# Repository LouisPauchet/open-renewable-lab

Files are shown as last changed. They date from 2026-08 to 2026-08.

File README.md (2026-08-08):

# Walter Sensor Node — Open Renewable Lab (UNIS)

ESP-IDF firmware for a student-configurable environmental datalogger/gateway
built on the Walter ESP32-S3 module + Walter Feels carrier board: SDI-12 and
I2C sensors (including a built-in PV voltage/current sensing input), SD card
logging, MQTT (WiFi or cellular transport), GNSS position logging (cellular
only), scheduled batch MQTT transmission for power saving, and a
captive-portal web UI for setup - no code changes needed per deployment.

Every device has a stable ID derived from its factory MAC address, shown in
the portal's status panel, written into every CSV file's header line, and
included in every MQTT topic (`<topic_prefix>/<device_id>/<variable name>`)
so multiple nodes can share one broker/topic_prefix.

📖 **Full documentation site:** https://\<OWNER\>.github.io/\<REPO\>/ — start
there for a browsable version of everything below, including a
[step-by-step guide to wiring up a 20 W solar panel and getting data into
ThingsBoard](docs/getting-started.md).

## Get firmware onto a board — no ESP-IDF required

Every [release](https://github.com/<OWNER>/<REPO>/releases) publishes a
ready-to-flash binary. Flash it from your browser (Chrome/Edge, no installs)
or with `esptool` — see **[docs/firmware-downloads.md](docs/firmware-downloads.md)**.
The steps below (`idf.py build`) are only needed if you're modifying the
firmware source.

## Documentation

- **[docs/getting-started.md](docs/getting-started.md)** - wiring up a real
  20 W RS PRO solar panel (voltage + current sensing) and getting its data
  into ThingsBoard over MQTT, start to finish.
- **[docs/USER_MANUAL.md](docs/USER_MANUAL.md)** - deploying and operating a
  device via the web portal. No code or ESP-IDF knowledge needed; start here
  if you're a student setting up a sensor station.
- **[docs/hardware.md](docs/hardware.md)** - photos of the physical
  enclosure, what each external connector is for, and links to the
  KiCad/CAD source.
- **[docs/firmware-downloads.md](docs/firmware-downloads.md)** - getting
  pre-built firmware onto a board without installing ESP-IDF.
- **[docs/DEVELOPER_GUIDE.md](docs/DEVELOPER_GUIDE.md)** - firmware
  architecture, component reference, REST API, concurrency model, and how to
  extend the code (e.g. add a new sensor driver). Start here if you're
  reading or modifying the source.

## Prerequisites

- ESP-IDF **v6.0.2**, target `esp32s3`.
- Network access at build time: `dptechnics/walter-modem` is fetched from the
  ESP Component Registry via `main/idf_component.yml`.
- **Check your ESP-IDF install has the `mqtt` component's source** before
  building: `components/mqtt/esp-mqtt/include` should exist. If it doesn't
  (missing submodule), re-run the ESP-IDF installer / `git submodule update`
  first - this was missing in the environment this firmware was written in,
  so it was never build-tested end-to-end.

## Build

```
idf.py set-target esp32s3
idf.py build
idf.py -p <PORT> flash monitor
```

**No Walter Feels board yet?** You can test the firmware on a plain ESP32
DevKit V1 with I2C sensors (e.g. two ADS1115 ADCs) instead - see
[DEVELOPER_GUIDE.md §19](docs/DEVELOPER_GUIDE.md#19-testing-without-walter-feels-hardware).

## Before first flash: check `board_pins.h`

`components/board_pins/include/board_pins.h` holds every Walter Feels GPIO
assignment. SDI-12, I2C, and SD card pin *numbers* come straight from the
schematic and are confirmed; enable-pin polarities and a few optional pins
(card-detect, status LED, force-AP button) are not - see
[DEVELOPER_GUIDE.md §8](docs/DEVELOPER_GUIDE.md#8-board-pin-mapping-board_pins)
for the full pin table and what's still open. Each subsystem safely no-ops
(logs a warning, falls back to a synthetic stub sensor where relevant) if
its required pins are left unset, so the firmware boots and the portal
works even before any of this is resolved.

For a full list of known low-confidence areas (cellular/GNSS integration,
the SDI-12 physical layer, etc.) that should be reviewed before a real
deployment, see
[DEVELOPER_GUIDE.md §18](docs/DEVELOPER_GUIDE.md#18-known-limitations-and-low-confidence-areas).

## First boot

See [USER_MANUAL.md](docs/USER_MANUAL.md) for the full walkthrough. Short
version: connect to the `WalterSensor-XXXX` WiFi hotspot, browse to
`http://192.168.4.1/` if the login page doesn't pop up automatically, log
in with the default password `walter1234`, and **change it immediately**.

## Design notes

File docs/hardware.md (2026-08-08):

# Hardware

This page documents the physical Open Renewable Lab enclosure — what's
inside it, what each external connector is for, and where to find the
CAD/schematic source if you're building or repairing one.

## The enclosure

<figure markdown>
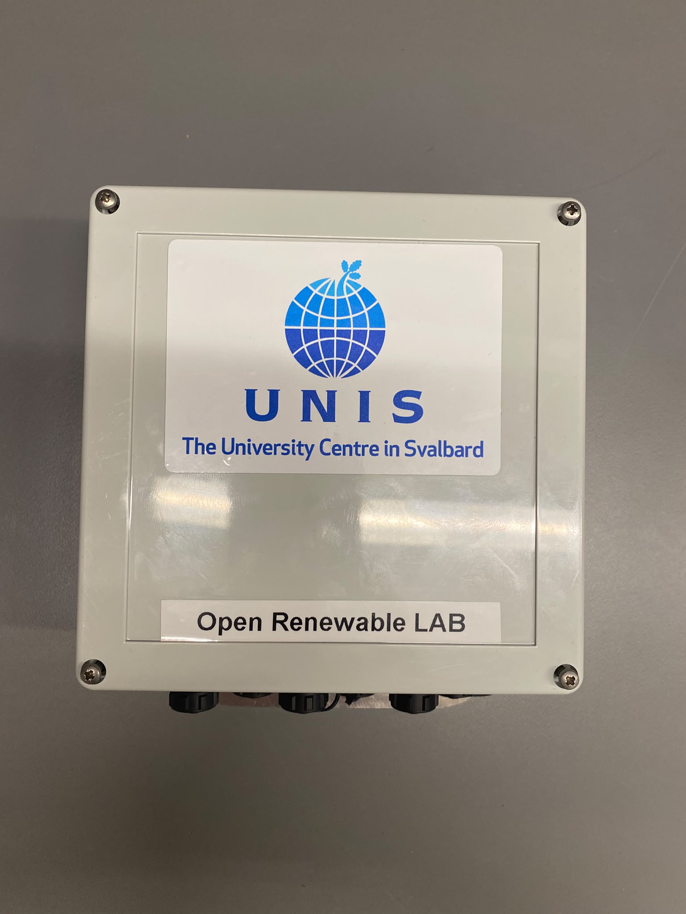
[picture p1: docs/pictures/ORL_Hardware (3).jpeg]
Open Renewable Lab enclosure lid, branded with the UNIS logo

<figcaption>
The enclosure lid: UNIS (The University Centre in Svalbard) branding and
the "Open Renewable LAB" label.
</figcaption>
</figure>

<figure markdown>
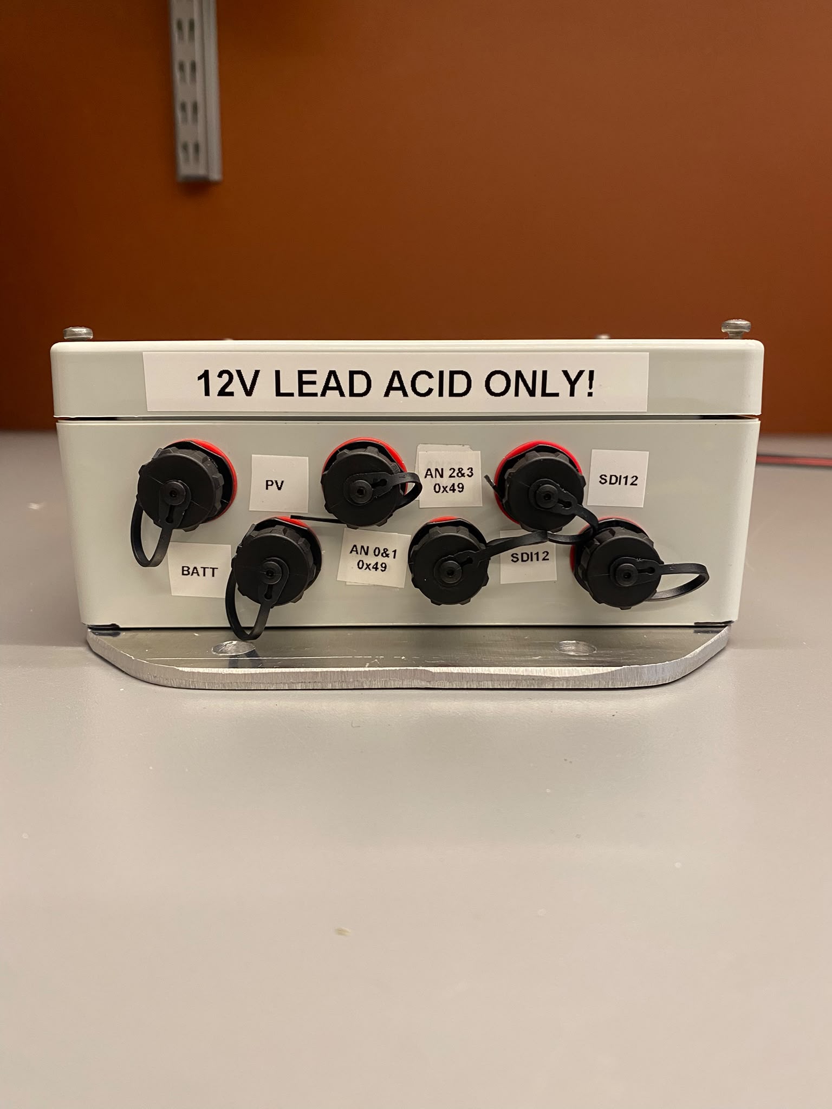
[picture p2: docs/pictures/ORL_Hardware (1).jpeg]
Open Renewable Lab enclosure, external connectors

<figcaption>
The enclosure's external cable glands, each labeled with what it connects
to. "12V LEAD ACID ONLY!" is a hardware constraint on the battery input —
the onboard LTC4015 charger circuit is built for a 12&nbsp;V lead-acid
battery specifically; check with your instructor before connecting a
different battery chemistry.
</figcaption>
</figure>

### Connector reference

| Label | Connects to | Notes |
|---|---|---|
| **PV** | A small auxiliary solar panel, wired straight to the onboard LTC4015 charger | Keeps the logger's *own* operating battery topped up. **Not a measurement input** — this is not where an instrumented/monitored panel goes; see **AN 0&1**/**AN 2&3** below for that. |
| **AN 0&1** (0x49) | A 4-pin instrumented sensor (e.g. the RS PRO panel in [Getting started](getting-started.md)), via the external ADS1115 ADC at I2C address `73` (`0x49`) | Exposes single-ended channels `AIN0`/`AIN1`. For the PV add-on: `AIN0` = voltage (divider output), `AIN1` = current (shunt voltage). |
| **AN 2&3** (0x49) | Same ADS1115, a second 4-pin instrumented sensor input | Exposes single-ended channels `AIN2`/`AIN3` — same wiring pattern as AN 0&1, for a second instrumented sensor (e.g. a second panel, a pyranometer). |
| **BATT** | The 12&nbsp;V lead-acid battery, read by the onboard LTC4015 battery monitor (I2C address `104`/`0x68`) | Set battery chemistry/cell count under the portal's **Battery monitor** settings — see [USER_MANUAL.md §6.5](USER_MANUAL.md#65-onboard-walter-feels-sensors-battery-temperature-humidity-pressure). |
| **SDI12** (×2) | External SDI-12 sensors (soil moisture, weather stations, etc.) | Multiple SDI-12 sensors can share one bus, each with its own address — see [USER_MANUAL.md §6.2](USER_MANUAL.md#62-finding-your-sensors-address). |

`AN 0&1`/`AN 2&3` are generic analog inputs — this enclosure is built on
the same base as the plain [datalogger](build_datalogger.md), with the PV
sensing add-on (ADS1115 + shunt + divider) wired to those two ports rather
than being a fixed, PV-only circuit.

⚠ **AN 0&1, AN 2&3, and BATT (the LTC4015) all need a battery connected
to work at all.** They share one I2C bus, powered from a "Feels 5V" rail
derived from the battery/PV input — USB alone doesn't power it. Bench
testing over USB only, with nothing on BATT, will make that whole bus
look dead/unresponsive; that's expected, not a fault.

## Inside the enclosure

<figure markdown>
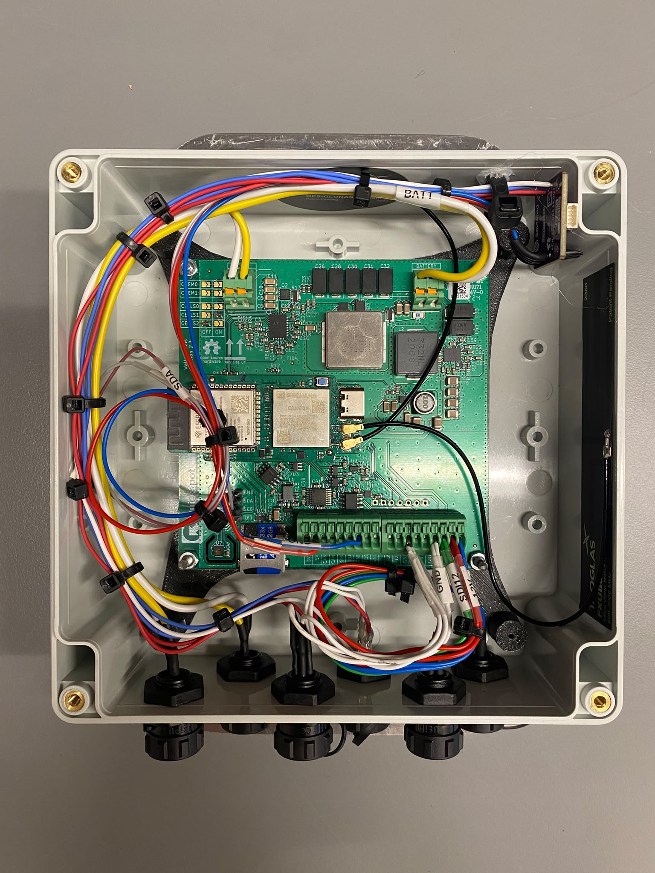
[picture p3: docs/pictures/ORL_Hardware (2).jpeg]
Open enclosure showing the Walter ESP32-S3 board and internal wiring

<figcaption>
The Walter ESP32-S3 module + Walter Feels carrier board, with the GNSS
antenna, battery connector, microSD slot, and the screw-terminal block used
for SDI-12 wiring.
</figcaption>
</figure>

## CAD and schematic source

The full KiCad project (schematic + PCB) for the sensing/interconnect board
lives in the repository under
[`hardware/open_renewable_lab/`](https://github.com/<OWNER>/<REPO>/tree/main/hardware/open_renewable_lab),
open it with [KiCad](https://www.kicad.org/) 8 or newer.

The 3D-printable/CNC enclosure mount is under
[`hardware/drawing/`](https://github.com/<OWNER>/<REPO>/tree/main/hardware/drawing):
`OpenRenewableLabMount.stl` (print-ready), `OpenRenewableLabMount.CATPart`
(CATIA source), and `OpenRenewableLabMount.3mf`.

For the firmware-side GPIO pin mapping that corresponds to this hardware
(SDI-12, I2C, SD card pins), see
[DEVELOPER_GUIDE.md §8](DEVELOPER_GUIDE.md#8-board-pin-mapping-board_pins).

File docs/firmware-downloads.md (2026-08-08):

# Firmware downloads

Every [GitHub Release](https://github.com/<OWNER>/<REPO>/releases) publishes
ready-to-flash firmware binaries automatically — you do **not** need to
install ESP-IDF or build anything to get firmware onto a board. Pick one of
the first two options below; the third is only for people modifying the
firmware source.

## Option 1: Flash from your browser (easiest)

Works in **Chrome or Edge** (desktop) via WebSerial — nothing to install.

1. Plug the board into your computer over USB.
2. Click the button below and follow the prompts (pick the right serial
   port, then "Install").

<script type="module" src="https://unpkg.com/esp-web-tools@10/dist/web/install-button.js"></script>

<esp-web-install-button manifest="../manifest.json">
  <button slot="activate">Connect and flash latest firmware</button>
  <span slot="unsupported">
    Your browser doesn't support WebSerial — use Chrome or Edge, or see
    Option 2 below.
  </span>
  <span slot="not-allowed">
    This page needs to be served over HTTPS to flash (the GitHub Pages
    site already is) — if you're seeing this locally, use Option 2.
  </span>
</esp-web-install-button>

This always flashes the **latest published release**. It erases the whole
flash (including any saved portal configuration) and writes the merged
firmware image in one shot, starting fresh — see
[USER_MANUAL.md](USER_MANUAL.md) afterwards for first-boot setup.

## Option 2: Flash with `esptool` (no ESP-IDF)

1. Install [`esptool`](https://docs.espressif.com/projects/esptool/en/latest/esp32/):
   ```sh
   pip install esptool
   ```
2. Download `walter_sensor_node.merged.bin` from the
   [latest release](https://github.com/<OWNER>/<REPO>/releases/latest).
3. Flash it to offset `0x0` (it already contains the bootloader, partition
   table, and application — no other files or offsets needed):
   ```sh
   esptool.py --chip esp32s3 --port <PORT> write_flash 0x0 walter_sensor_node.merged.bin
   ```
   Replace `<PORT>` with your board's serial port (e.g. `COM5` on Windows,
   `/dev/ttyUSB0` on Linux, `/dev/cu.usbserial-*` on macOS).

Each release also publishes the three components separately
(`bootloader.bin`, `partition-table.bin`, `walter_sensor_node.bin`) and a
`SHA256SUMS` file, in case you need to flash/verify them individually.

## Option 3: Build from source

Only needed if you're modifying the firmware itself. Requires installing
ESP-IDF v6.0.2 — see
[DEVELOPER_GUIDE.md §2](DEVELOPER_GUIDE.md#2-prerequisites-and-build).

## Which release should I use?

Use the [latest release](https://github.com/<OWNER>/<REPO>/releases/latest)
unless your instructor tells you otherwise (e.g. to match a specific lab
session or reproduce a known-good setup).

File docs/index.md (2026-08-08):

# Open Renewable Lab

The **Open Renewable Lab** is UNIS's (The University Centre in Svalbard)
student-configurable environmental datalogger/gateway, built on the Walter
ESP32-S3 module and the Walter Feels carrier board. It reads SDI-12 and I2C
sensors (including a built-in PV voltage/current sensing input), logs to a
microSD card, and publishes to an MQTT broker over WiFi or cellular — all
configured through a web page served by the device itself, with **no code
changes needed per deployment**.

Every device has a stable ID derived from its factory MAC address, shown in
the portal's status panel, written into every CSV file's header line, and
included in every MQTT topic, so multiple nodes can share one broker.

## Where to start

**Building the hardware from parts?** Step-by-step assembly of the
enclosure, wiring, and board — see
[Build a datalogger](build_datalogger.md).

**New to the lab?** Wiring up a real 20 W solar panel and getting live data
into ThingsBoard, start to finish — see
[Getting started](getting-started.md).

**Just need firmware on a board?** Flash a pre-built binary straight from
your browser or with `esptool` — no ESP-IDF install required — see
[Firmware downloads](firmware-downloads.md).

**Operating a device day-to-day?** Sensors, MQTT, SD logging, the web
portal — the full reference for anyone deploying or running a station — see
the [User manual](USER_MANUAL.md).

**Reading or modifying the firmware?** Architecture, component reference,
REST API, and how to extend the code — see the
[Developer guide](DEVELOPER_GUIDE.md).

## What it can do

- Read **SDI-12** sensors (soil moisture, weather stations, water level
  probes) and **I2C** sensors (ADCs, onboard battery/temperature/humidity/
  pressure sensors).
- Log everything to a **microSD card** as CSV files.
- Publish data to an **MQTT broker** over WiFi or cellular (4G/LTE-M/NB-IoT),
  including a ThingsBoard-compatible "flat telemetry" mode — see
  [Getting started](getting-started.md).
- Report **GPS position** over cellular.
- Be fully configured **without writing any code** — every sensor, timing
  setting, and network/MQTT credential is set through the device's own
  captive-portal web page.

## Hardware

The lab's physical build — enclosure, connectors, and PV sensing input — is
documented with photos on the [Hardware](hardware.md) page.

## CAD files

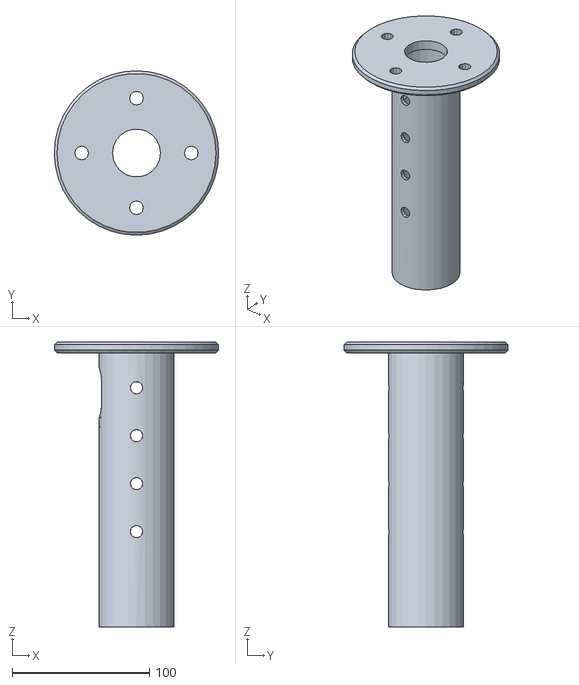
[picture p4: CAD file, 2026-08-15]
hardware/drawing/MountWindTurbine.stl
120.0 x 120.0 x 208.0

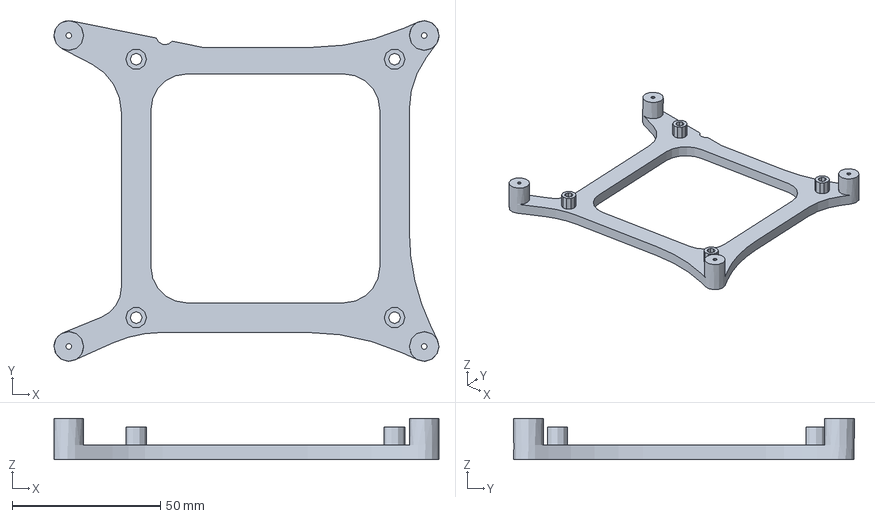
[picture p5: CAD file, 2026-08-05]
hardware/drawing/OpenRenewableLabMount.3mf
130.0 x 115.0 x 14.0 mm

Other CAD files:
hardware/drawing/MountWindTurbine.CATPart
hardware/drawing/OpenRenewableLabMount.CATPart
hardware/drawing/OpenRenewableLabMount.stl

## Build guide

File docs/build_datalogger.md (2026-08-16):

# Let's use this project to build a data logger capable to use any SDI12 sensors.

## What do you need ?

The numbers below match the callouts on the component photo referenced
throughout the steps that follow.

1 - Walter Feels Carrier Board https://www.gotronic.fr/art-module-walter-feels-39900.htm
2 - Walter ESP32 https://www.gotronic.fr/art-carte-walter-esp32-s3-39898.htm
3 - A box RSPRO 672365 https://fr.rs-online.com/web/p/boitiers-pour-usage-general/0672365
4 - A 3D printed support to hold the walter feels in the box
5 - 1 or more SP11 3 Pin connectors (Male and Female) (SDI12 Sensors)
6 - 2x SP11 2 Pin connectors (Male and Female) (Battery and Solar Panel)
7 - Wires
8 - LTE Antenna TAOGLAS FXUB63 https://www.gotronic.fr/art-antenne-flexible-4g-et-5g-fxub63-39916.htm
9 - GNSS Antenna TAOGLAS FXP-611 https://www.gotronic.fr/art-antenne-cloud-gnss-fxp611-39917.htm
10 - A pokawoke to drill in the box (available in AGF dept if you are at UNIS)

<figure markdown>
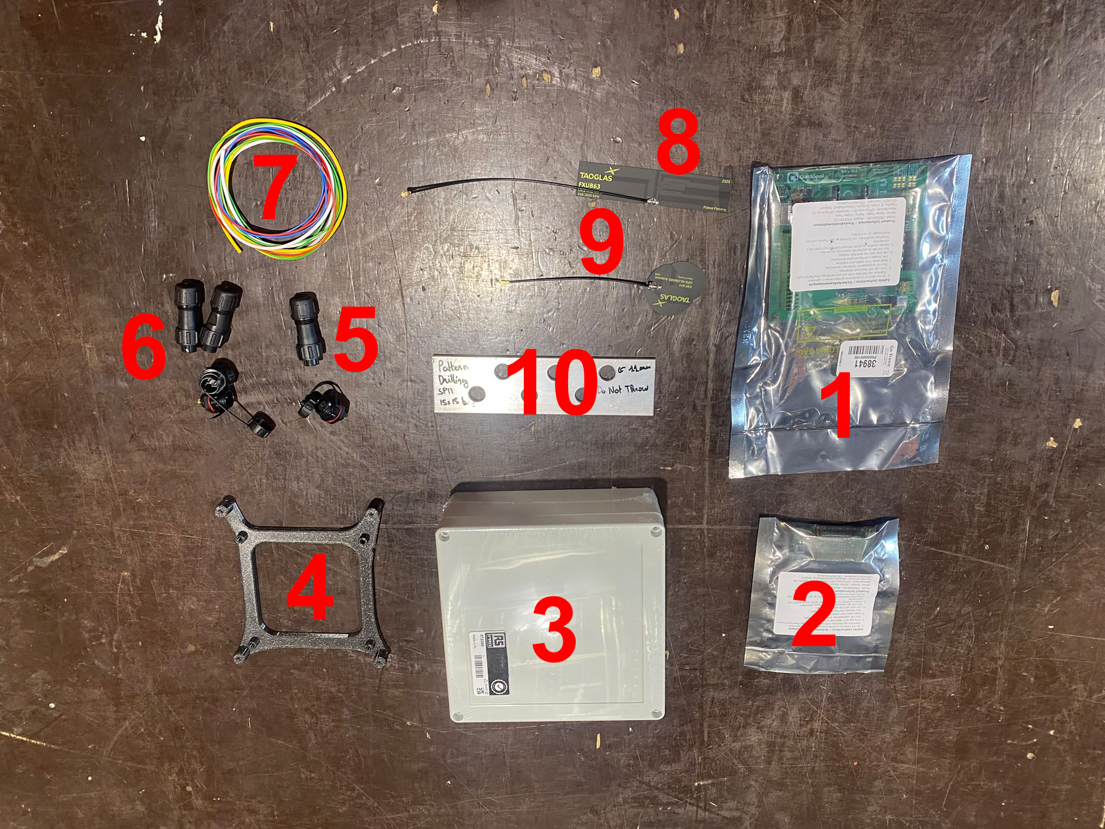
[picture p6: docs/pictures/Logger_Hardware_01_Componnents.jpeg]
Componnent List

<figcaption>
Componnent List
</figcaption>
</figure>

You'll also need a soldering iron, heat shrink tubing (+ a lighter or hot
air gun to shrink it), wire strippers, and a screwdriver.

This page builds the **generic datalogger** - Walter, Walter Feels, box,
antennas, battery/solar charging power, and SDI-12. It does not cover the
ADS1115 analog-input add-on (the two 4-pin "AN1"/"AN2" connectors reading
an instrumented source like a solar panel's or wind turbine's voltage/
current) - if you're building an **Open Renewable Lab** station
specifically, come back to
[Getting started](getting-started.md) and [Hardware](hardware.md) once
this base build is done.

## Building it

### 1. Drill the enclosure

<figure markdown>
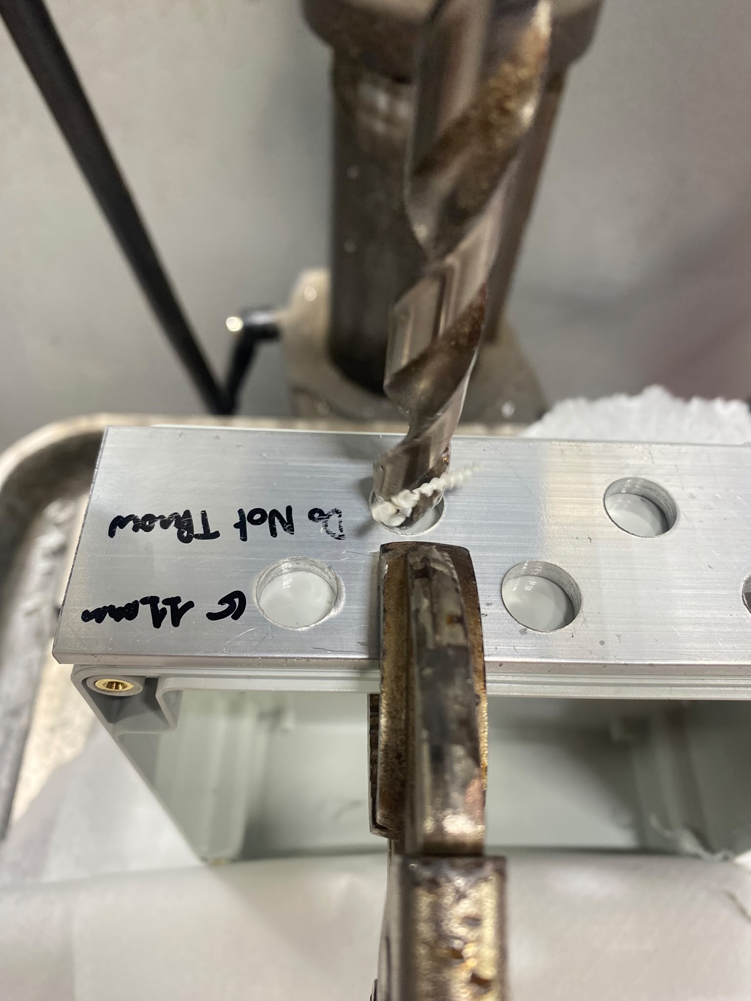
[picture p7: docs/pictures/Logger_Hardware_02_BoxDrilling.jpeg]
Drilling the SP11 connector holes using a jig

<figcaption>
Drilling the box (item 3) for the SP11 connectors, using a reusable
drilling jig/template (labeled "Pattern Drilling SP11 - Do Not Throw") to
keep every hole's position and spacing consistent across builds.
</figcaption>
</figure>

### 2. Solder the power plugs (battery + solar charging)

<figure markdown>
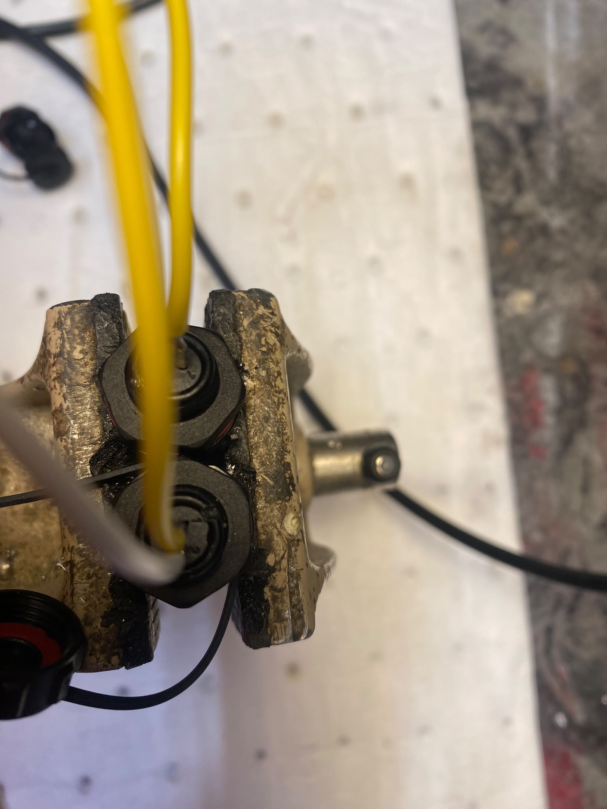
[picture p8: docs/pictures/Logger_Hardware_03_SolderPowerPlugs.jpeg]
Soldering wires onto an SP11 2-pin connector

<figcaption>
Soldering wires onto the two SP11 2-pin connectors (item 6) - one for the
battery, one for the solar panel that charges it. Get the polarity right
and consistent between both connectors before shrinking anything down over
the joints.
</figcaption>
</figure>

<figure markdown>
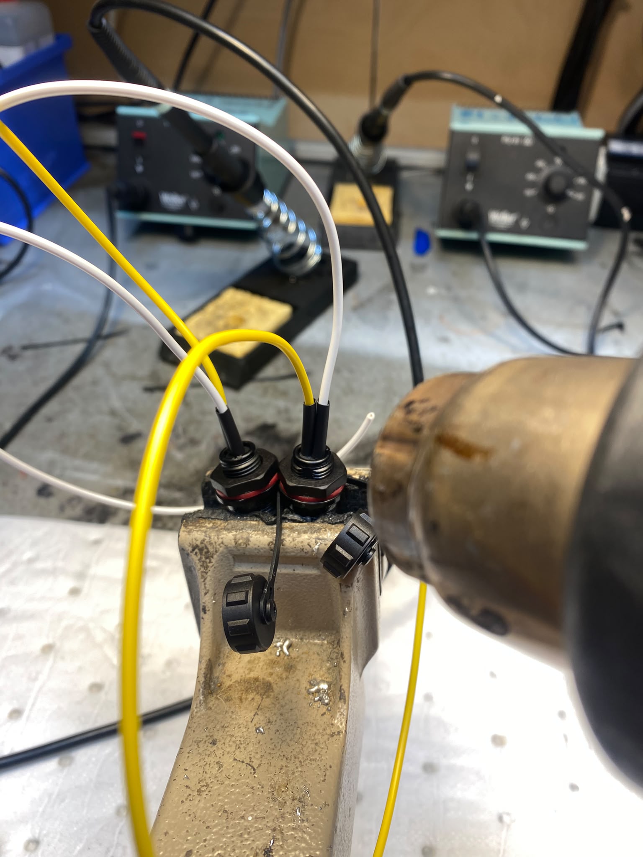
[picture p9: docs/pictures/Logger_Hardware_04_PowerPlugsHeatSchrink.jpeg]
Heat-shrink tubing over the finished power plug solder joints

<figcaption>
Heat-shrink over each solder joint once you're happy with it - both for
strain relief and to keep the two adjacent pins from ever shorting.
</figcaption>
</figure>

### 3. Solder the SDI-12 plug(s)

<figure markdown>
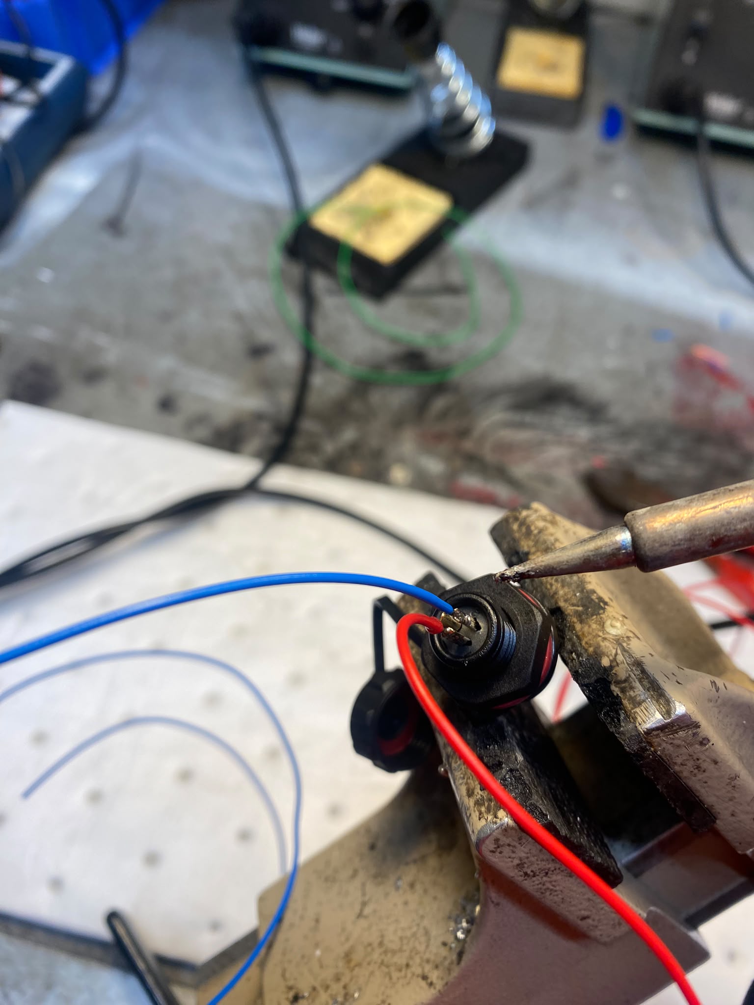
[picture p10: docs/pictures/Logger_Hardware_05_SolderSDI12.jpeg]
Soldering wires onto an SP11 3-pin connector for SDI-12

<figcaption>
Same idea for the SP11 3-pin connector(s) (item 5) - one per SDI-12 port
you want on the box (three wires: signal, power, ground).
</figcaption>
</figure>

<figure markdown>
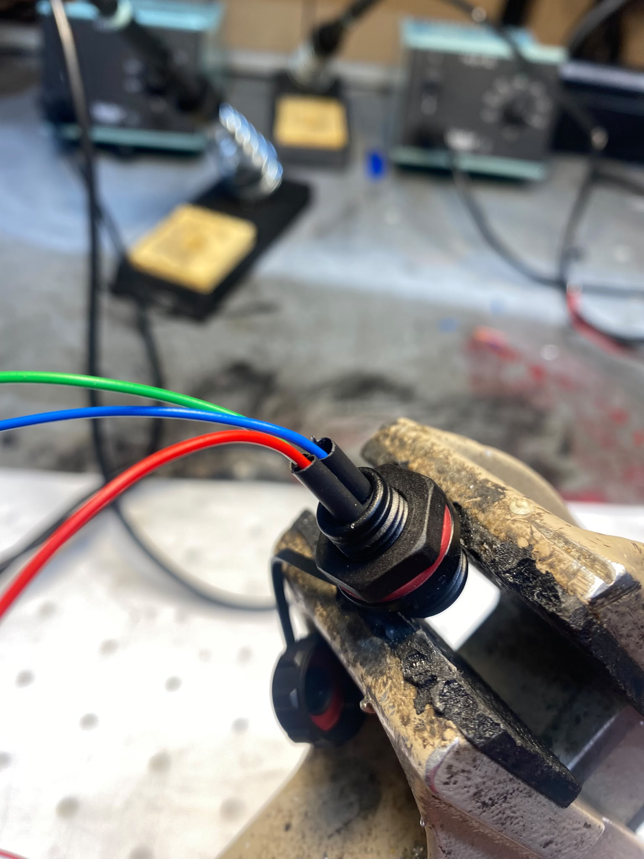
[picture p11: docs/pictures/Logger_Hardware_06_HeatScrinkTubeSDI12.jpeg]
Heat-shrink tubing over the SDI-12 connector's solder joints

<figcaption>
Heat-shrink these joints too before moving on.
</figcaption>
</figure>

### 4. Mount all the plugs in the enclosure

<figure markdown>
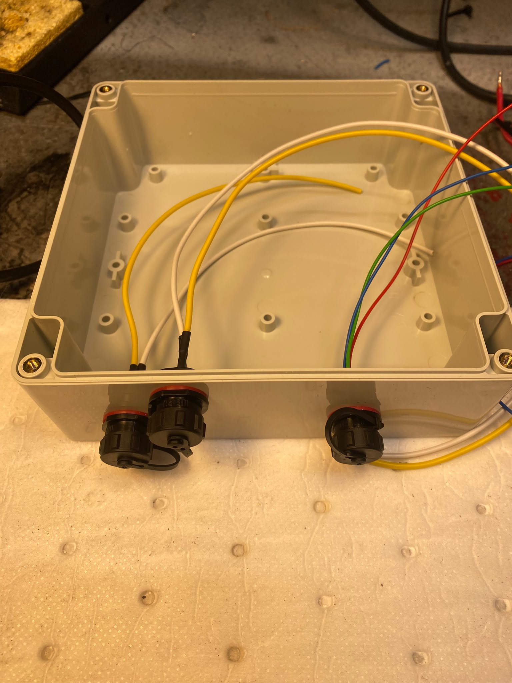
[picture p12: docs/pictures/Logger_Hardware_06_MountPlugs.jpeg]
All finished connectors mounted through the drilled enclosure

<figcaption>
Feed each finished connector through its drilled hole and tighten it down
- gland-nut side out, wires trailing inside the box, ready to reach the
board once it's mounted.
</figcaption>
</figure>

### 5. Mount the board and connect the antennas

Screw the 3D-printed support (item 4) into the enclosure, then mount the
Walter + Walter Feels board onto it. Connect the LTE antenna (item 8,
TAOGLAS FXUB63) and the GNSS antenna (item 9, TAOGLAS FXP-611) to their
u.FL connectors on the board, and route both antenna cables to wherever
you're mounting the antennas themselves on/outside the enclosure.

### 6. Wire the plugs to the board

<figure markdown>
Finished internal wiring: battery, SDI-12, and antenna connections to the Walter Feels screw terminals
<figcaption>
Connect each plug's wires to the matching screw terminal on the Walter
Feels board - battery to the <code>BATTERY</code> terminal, SDI-12 signal/
power/ground to the labeled <code>SDI12</code>/<code>GND</code>/<code>12V</code>
terminals. This example board also has the optional analog add-on wired
in (not part of this base build) - yours will just have the battery,
solar charging, and SDI-12 connections at this stage.
</figcaption>
</figure>

### 7. Label the enclosure

<figure markdown>
Labeled enclosure connectors and battery-compatibility warning
<figcaption>
Label every external connector so nobody has to guess later, and mark the
battery chemistry the box is built for - Walter Feels' onboard LTC4015
charger is configured for one chemistry at a time (see
[USER_MANUAL.md §6.5](USER_MANUAL.md#65-onboard-walter-feels-sensors-battery-temperature-humidity-pressure)),
so a clear warning label prevents someone plugging in the wrong battery
type. This example also shows the optional AN1/AN2 analog inputs - skip
those two labels if you're not adding that piece.
</figcaption>
</figure>

### 8. Seal the cable lead-through

<figure markdown>
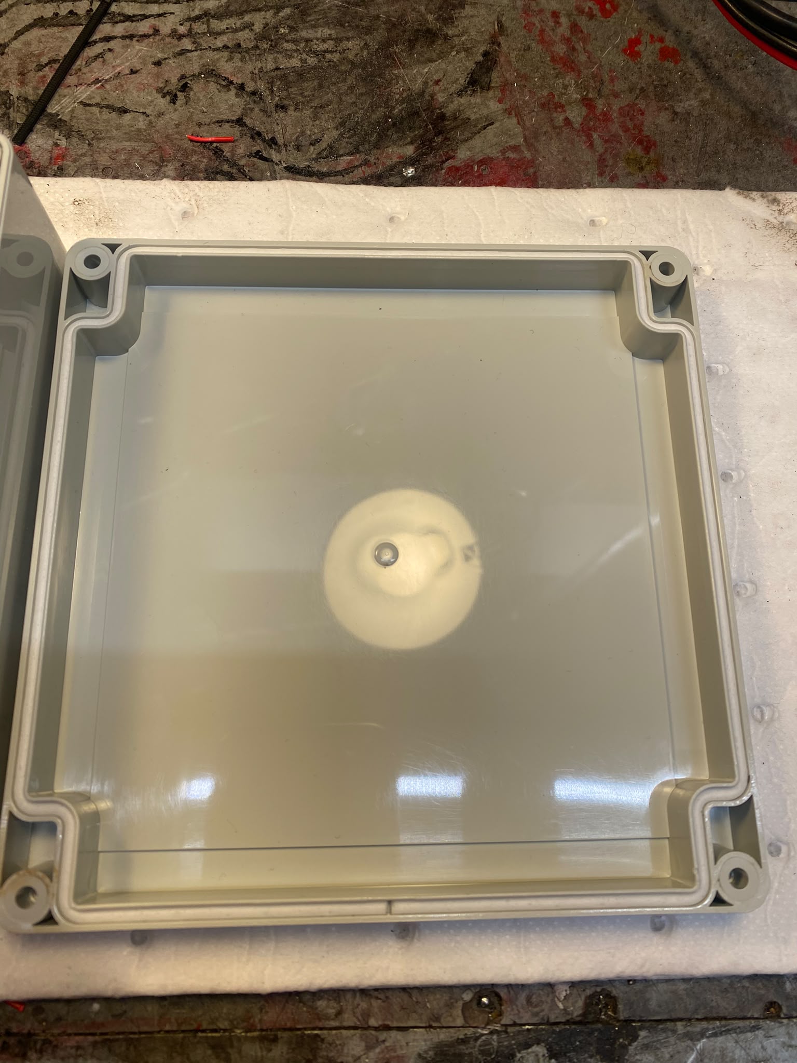
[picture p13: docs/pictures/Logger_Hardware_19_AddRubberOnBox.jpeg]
Adding a rubber grommet to the enclosure

<figcaption>
A rubber grommet/gasket around the cable lead-through - this is what keeps
that entry point water-tight, not a cosmetic touch, so don't skip it even
on an indoor build.
</figcaption>
</figure>

### 9. Insert the microSD card

<figure markdown>
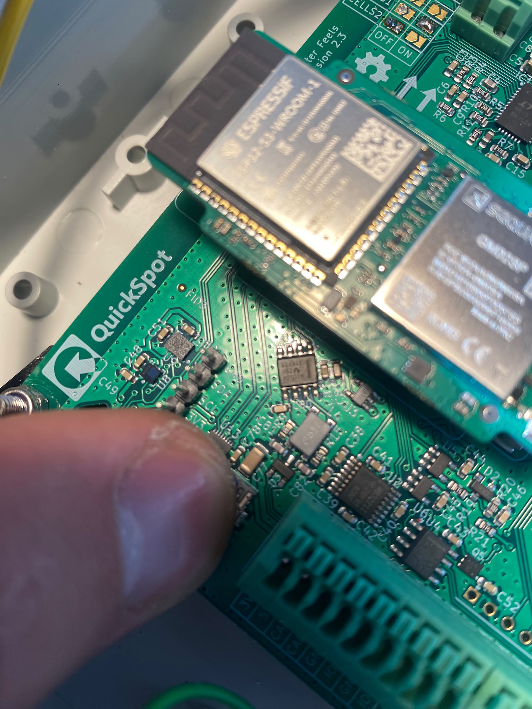
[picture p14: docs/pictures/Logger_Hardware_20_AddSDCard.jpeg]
Inserting the microSD card into the Walter Feels board

<figcaption>
Insert a FAT32-formatted microSD card into the slot on the board - this is
where sensor data gets logged locally regardless of whether MQTT is set
up (see [USER_MANUAL.md §10.1](USER_MANUAL.md#101-on-the-sd-card)).
</figcaption>
</figure>

### 10. Insert the SIM card (cellular only)

<figure markdown>
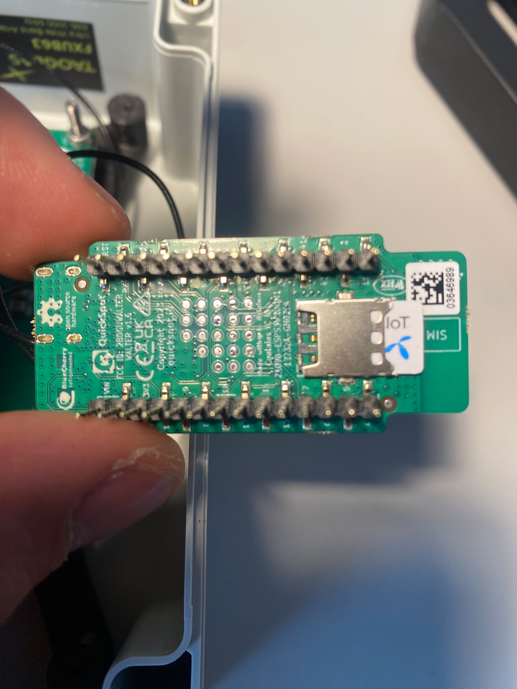
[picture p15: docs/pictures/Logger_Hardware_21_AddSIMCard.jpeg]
Inserting a SIM card into the Walter module

<figcaption>
Only needed if you're using cellular data instead of WiFi - insert your
IoT/M2M SIM into the Walter module's SIM slot before closing up the box.
</figcaption>
</figure>

## Next steps

Close up the enclosure and you have a working generic datalogger. From
here:

- [Firmware downloads](firmware-downloads.md) - get firmware onto the
  board if it isn't already flashed.
- [User Manual](USER_MANUAL.md) - first boot, connecting to the setup
  hotspot, and configuring SDI-12 sensors, MQTT, and networking.
- Building an **Open Renewable Lab** station specifically (the ADS1115
  analog add-on for instrumenting a solar panel and/or wind turbine)?
  Continue with [Getting started](getting-started.md).

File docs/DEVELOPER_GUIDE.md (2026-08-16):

# Walter Sensor Node — Developer Guide

This guide explains how the firmware is put together, for anyone reading,
modifying, or extending the code. If you just want to *use* a device, see
[USER_MANUAL.md](USER_MANUAL.md) instead.

It assumes basic C familiarity but not prior ESP-IDF/embedded experience —
unfamiliar terms are explained inline or in the [glossary](#21-glossary)
at the end.

---

## Table of contents

1. [Goals and constraints](#1-goals-and-constraints)
2. [Prerequisites and build](#2-prerequisites-and-build)
3. [Project layout](#3-project-layout)
4. [Architecture overview](#4-architecture-overview)
5. [Boot sequence](#5-boot-sequence)
6. [Concurrency model](#6-concurrency-model)
7. [Configuration system (`config_store`)](#7-configuration-system-config_store)
8. [Board pin mapping (`board_pins`)](#8-board-pin-mapping-board_pins)
9. [Sensor buses](#9-sensor-buses)
10. [Sampling and aggregation (`sampling_engine`)](#10-sampling-and-aggregation-sampling_engine)
11. [SD logging (`sd_logger`)](#11-sd-logging-sd_logger)
12. [Networking (`net_manager`)](#12-networking-net_manager)
13. [MQTT (`mqtt_client`)](#13-mqtt-mqtt_client)
14. [Cellular integration (`cellular_transport`)](#14-cellular-integration-cellular_transport)
15. [Position reporting (`gnss_position`)](#15-position-reporting-gnss_position)
16. [Device identification (`device_id`)](#16-device-identification-device_id)
17. [Web portal (`web_portal`)](#17-web-portal-web_portal)
18. [Known limitations and low-confidence areas](#18-known-limitations-and-low-confidence-areas)
19. [Testing without Walter Feels hardware](#19-testing-without-walter-feels-hardware)
20. [How to extend the firmware](#20-how-to-extend-the-firmware)
21. [Glossary](#21-glossary)

---

## 1. Goals and constraints

This firmware is a **student-configurable environmental sensor node**: the
goal is that a student deploying a new station never needs to touch the
source code or reflash firmware — every sensor, timing setting, and network
credential is set through a captive-portal web UI (see
[USER_MANUAL.md](USER_MANUAL.md)).

A few decisions run through the whole codebase and are worth knowing before
you start reading source:

- **No OTA in v1** — a single factory app partition, no update mechanism.
  Reflashing is done over USB.
- **Config changes apply live where reasonably possible.** Most settings
  (variables, MQTT, position) take effect immediately via a
  generation-counter change-detection pattern (see [section 7](#7-configuration-system-config_store)).
  Only network *transport* (WiFi ↔ Cellular ↔ unconfigured) requires a
  reboot, to avoid the complexity of live-tearing-down the WiFi/modem stack.
- **Graceful degradation over hard failure.** If a board pin isn't
  configured, or a card/sensor isn't present, the affected subsystem logs a
  warning and disables itself rather than blocking boot or crashing — see
  [section 8](#8-board-pin-mapping-board_pins).
- **One FreeRTOS task per hardware resource**, not per feature — e.g. one
  task owns the I2C bus and services requests from other components via
  narrow interfaces, rather than several tasks reaching into the bus driver
  directly. See [section 6](#6-concurrency-model).

---

## 2. Prerequisites and build

- ESP-IDF **v6.0.2**, target `esp32s3`.
- Network access at build time: `dptechnics/walter-modem` is a managed
  dependency fetched from the ESP Component Registry (declared in
  `main/idf_component.yml`).
- **Your ESP-IDF install must have the `mqtt` component's source** —
  check `components/mqtt/esp-mqtt/include` exists under your ESP-IDF path.
  This was missing in the environment this firmware was originally written
  in (a submodule that hadn't been fetched), so parts of `mqtt_client` were
  written against documented API behavior rather than checked headers — see
  [section 18](#18-known-limitations-and-low-confidence-areas).

```sh
idf.py set-target esp32s3
idf.py build
idf.py -p <PORT> flash monitor
```

Before flashing onto real hardware, read [section 8](#8-board-pin-mapping-board_pins)
— some GPIO assignments are still placeholders.

---

## 3. Project layout

```
open_renewable_lab/
├── CMakeLists.txt, sdkconfig.defaults, partitions.csv
├── main/
│   ├── app_main.c          # init order + task spawn only, no business logic
│   └── idf_component.yml   # declares the walter-modem managed dependency
├── docs/
│   ├── USER_MANUAL.md
│   └── DEVELOPER_GUIDE.md  # this file
└── components/
    ├── board_pins/         # GPIO assignment header, single source of truth
    ├── device_id/          # MAC-derived unique device identifier
    ├── config_store/       # NVS-backed config, JSON (de)serialization
    ├── sampling_engine/    # per-bus scheduling + Welford aggregation
    ├── stub_sensor/        # synthetic sensor source for testing w/o hardware
    ├── sdi12_bus/          # bit-banged SDI-12 physical layer + protocol
    ├── i2c_bus/            # driver/i2c_master.h wrapper (external I2C connector)
    ├── onboard_i2c_bus/    # second, separate driver/i2c_master.h wrapper - reserved for
    │                       # Walter Feels' optional/unpopulated CO2 (SCD30) + LSM6DSM IMU
    │                       # header (GPIO12/11); NOT where HDC1080/LPS22HB live (see §9.2)
    ├── i2c_sensors/        # per-device-type driver registry (ADS111x, HDC1080, LPS22HB, LTC4015, ...)
    ├── sd_logger/          # SDMMC mount + CSV writer
    ├── net_manager/        # WiFi AP+STA, always-on-AP policy
    ├── time_sync/          # SNTP client, shared "is time synced" definition
    ├── mqtt_client/        # transport-agnostic MQTT bridge, two backends
    ├── cellular_transport/ # WalterModem wrapper: registration, PDP, GNSS
    ├── gnss_position/      # periodic GNSS fix -> SD + MQTT
    └── web_portal/         # captive DNS, HTTP server, REST API, embedded SPA
```

Each component maps to one hardware resource or one cross-cutting concern.
`sampling_engine` never touches bus hardware directly — it calls through
`sdi12_bus`/`i2c_bus` via a registered function pointer — so sensors,
storage, and networking stay independently testable and swappable.

---

## 4. Architecture overview

```
                    ┌──────────────┐
                    │   app_main   │  init order + task spawn only
                    └──────┬───────┘
      ┌──────────┬─────────┼─────────┬───────────┬─────────────┐
      ▼          ▼         ▼         ▼           ▼             ▼
 board_pins  config_store  sdi12_bus  i2c_bus  sampling_    sd_logger
 (headers)   (NVS+JSON)              i2c_sensors  engine
                                                    │
                    ┌───────────────────────────────┼──────────────┐
                    ▼                                ▼              ▼
              net_manager                      mqtt_client    sd_logger
              (AP + STA)                     (dual backend)   (CSV sink)
                    │                                │
                    ▼                                ▼
              web_portal                     cellular_transport
           (REST API + SPA)                  (WalterModem, GNSS)
                                                       │
                                                       ▼
                                                 gnss_position
```

Everything the student configures lives in `config_store` (a single
in-RAM `device_config_t`, mirrored to NVS flash). Every other component
either reads from it directly (e.g. `sampling_engine` re-reads the variable
list each scheduling tick) or is notified of changes via its generation
counter (see [section 7.3](#73-the-generation-counter-pattern)).

---

## 5. Boot sequence

`main/app_main.c` is deliberately just an init-order/task-spawn list, no
business logic. Exact sequence:

1. Log chip info (cores, revision, flash size, free heap) and the device ID.
2. `config_store_init()` — mounts NVS, loads (or defaults) the config.
3. `config_store_get_snapshot()` — a local copy used for the rest of boot
   (safe because `net.transport` can't change without a reboot anyway).
4. `sdi12_bus_init()` — if it fails (pins unset), falls back to
   `stub_sensor_read` for `BUS_TYPE_SDI12` instead of the real driver.
5. `i2c_bus_init()` — same fallback pattern for `BUS_TYPE_I2C`.
6. `sampling_engine_init()` — spawns the bus-scheduler and aggregation
   tasks (drivers were already registered in steps 4-5).
7. A small debug task registers as a result sink and logs every finalized
   aggregate to the serial console — always active, useful during bring-up.
8. `sd_logger_init()` — best-effort; registers as a result sink on success,
   logs a warning and continues on failure (no card, pins unset, etc).
9. `net_manager_init()` — brings up the SoftAP (always) and WiFi STA (only
   if `transport == TRANSPORT_WIFI`).
10. `web_portal_init()` — starts the captive-portal DNS hijack and HTTP
    server.
11. `time_sync_init()` — starts the SNTP client (opportunistic, harmless
    without connectivity).
12. If `transport == TRANSPORT_CELLULAR`: `cellular_transport_init()`, and
    only on its success, `gnss_position_init()`.
13. `mqttc_init()` — always called; registers as a result sink and picks
    a backend (or `NULL` if transport is unconfigured, in which case MQTT
    stays fully inert).

Notice steps 4-8 all use the same pattern: **attempt init, register the
real driver/sink on success, fall back to a safe default (stub driver, or
simply not registering a sink) on failure** — nothing in this list can
abort boot.

---

## 6. Concurrency model

FreeRTOS tasks in this firmware, and what owns what:

| Task | Component | Owns / does | Notes |
|---|---|---|---|
| `sdi12_sched` | sampling_engine | SDI-12 bus scheduling | Sole caller of `sdi12_bus` from the periodic path |
| `i2c_sched` | sampling_engine | I2C bus scheduling | Sole caller of `i2c_bus` from the periodic path |
| `aggregation` | sampling_engine | Per-variable Welford accumulators | Registered with the task watchdog |
| `debug_sink` | main | Logs every aggregate to console | |
| `sd_writer` | sd_logger | All SD card file I/O | Registered with the task watchdog |
| (esp_wifi/lwIP internal tasks) | net_manager | WiFi driver | Not application-owned |
| `sta_reconnect` (esp_timer, not a task) | net_manager | STA reconnect backoff | One-shot timer, not a persistent task |
| `mqtt_pub` | mqtt_client | All MQTT connect/publish/disconnect calls | Registered with the task watchdog |
| `cellular` | cellular_transport | Registration status polling | |
| `gnss_pos` | gnss_position | Periodic GNSS fix acquisition | **Not** watchdog-registered (see below) |
| `httpd` (esp_http_server internal) | web_portal | HTTP request handling | |
| `dns_hijack` | web_portal | UDP:53 captive-portal DNS | |

### 6.1 Bus ownership, not mutexes, for periodic access

Rather than guarding `sdi12_bus`/`i2c_bus` with a mutex that any task could
contend for, each bus's *periodic* scheduling is owned by exactly one task
(`sdi12_sched`/`i2c_sched` inside `sampling_engine`). Both driver
components still carry an **internal mutex** of their own, though — not to
arbitrate between the sched tasks (there's only one caller each in the
periodic path), but because **on-demand callers** (the web portal's
Preview/Scan buttons, called from the HTTP server's own task) need to be
safely serialized against whichever sched task might currently be mid-
transaction. So: single owner for the periodic path, mutex for cross-task
safety against ad hoc callers.

### 6.2 Fan-out via result sinks

`sampling_engine` finalizes an `aggregate_result_t` per variable per log
interval and pushes a **copy** to every registered sink queue (up to
`MAX_RESULT_SINKS = 4`: currently the debug logger, `sd_logger`, and
`mqtt_client`). Sends are non-blocking (`xQueueSend(..., 0)`) — a slow or
stalled sink drops its own copy (logged) rather than ever blocking
`aggregation_task` or the other sinks.

### 6.3 Task watchdog registration

`aggregation_task`, `sd_writer_task`, and `mqtt_publish_task` are
registered with ESP-IDF's task watchdog (`CONFIG_ESP_TASK_WDT_TIMEOUT_S=15`,
`CONFIG_ESP_TASK_WDT_PANIC=y` — a genuine hang panics and reboots, since
this is meant for unattended field operation). They all have per-iteration
blocking bounded well under 15 seconds.

`sdi12_sched`/`i2c_sched` and `gnss_pos` are **deliberately not**
registered: a single sensor read (especially SDI-12's `aM!`-then-wait-then-
`aD0!` sequence, capped at `SDI12_MAX_MEASURE_WAIT_S = 180` seconds) or a
cold GNSS fix (`GNSS_FIX_TIMEOUT_MS = 60000`) can legitimately block far
longer than the watchdog timeout, and that's expected behavior, not a hang.

---

## 7. Configuration system (`config_store`)

### 7.1 Schema

The entire device configuration is one struct, `device_config_t`
(`components/config_store/include/config_schema.h`):

```c
typedef struct {
    uint32_t schema_version;
    char portal_password_hash[96];   // salt(16 hex) + sha256(64 hex)
    net_settings_t net;
    mqtt_settings_t mqtt;
    position_settings_t position;
    variable_config_t variables[MAX_VARIABLES];  // MAX_VARIABLES = 32
    uint8_t variable_count;
    uint32_t generation;
} device_config_t;
```

`variable_config_t` uses a union keyed by `bus_type` for the
bus-specific address fields (`sdi12_addr_t` = address char + parameter
index; `i2c_addr_t` = I2C address + device type + channel index).

### 7.2 Persistence

`config_store` keeps exactly one in-RAM copy (`s_config`), guarded by a
mutex, and mirrors it to NVS as a **single serialized JSON blob** (namespace
`"cfg"`, key `"device_json"`) rather than flat NVS key-value pairs — the
schema is nested/list-shaped (variables array, sub-structs), which flat NVS
keys handle awkwardly. `config_store_to_json()`/`config_store_from_json()`
are exported publicly precisely so `web_portal`'s REST handlers (variables
CRUD, settings export/import) reuse the *exact same* mapping — the wire
format and the persisted format can never drift apart.

On first boot, a missing NVS entry, or a corrupt/unparseable blob,
`config_store` falls back to safe compiled-in defaults
(`config_set_defaults()`): unconfigured transport, MQTT disabled, zero
variables, and the portal password hashed from `DEFAULT_PORTAL_PASSWORD`
(`"walter1234"`).

### 7.3 The generation counter pattern

Every mutating call (`config_store_add_variable`, `config_store_set_mqtt_settings`,
etc.) increments `s_config.generation` and persists to NVS before
returning. Other tasks that need to react to config changes — but don't
want to take a lock on every scheduling tick — instead compare
`config_store_get_generation()` against a locally-cached "last seen" value
each loop iteration, and only re-fetch/re-process the relevant settings
when it differs. `sampling_engine`'s bus-scheduler and aggregation tasks,
and `mqtt_publish_task`, all use this exact pattern.

### 7.4 Accessor API shape

For each settings group, `config_store.h` exposes a `get`/`set` pair that
copies the whole sub-struct in/out under the mutex (never hands out a
pointer into live state):

```c
void config_store_get_mqtt_settings(mqtt_settings_t *out);
esp_err_t config_store_set_mqtt_settings(const mqtt_settings_t *settings);
```

Same shape for `net_settings_t` and `position_settings_t`. Variables get
full CRUD (`get_variables` / `get_variable` / `add_variable` /
`update_variable` / `delete_variable`) since they're a list, not a
singleton.

---

## 8. Board pin mapping (`board_pins`)

`components/board_pins/include/board_pins.h` is the **single source of
truth** for every GPIO number — no other component hardcodes a pin number.

It has two `#if`-branched variants selected via a Kconfig choice
(`components/board_pins/Kconfig.projbuild`, menuconfig → "Walter Sensor
Node Board Selection"): the production Walter Feels mapping (below), and a
minimal I2C-only mapping for testing on a plain ESP32 DevKit V1 without a
Walter Feels board in hand — see
[section 19](#19-testing-without-walter-feels-hardware) for that workflow.

Most pins are now confirmed against the actual Walter Feels schematic
(supplied mid-project):

| Signal | GPIO | Notes |
|---|---|---|
| `BOARD_PIN_SDI12_TXD` | 40 | `SER_TX` — through a tri-state buffer (U5) onto the SDI-12 bus |
| `BOARD_PIN_SDI12_RXD` | 41 | `SER_RX` — from the bus through a second buffer (U6) |
| `BOARD_PIN_SDI12_TX_EN` | 10 | Asserted only while transmitting |
| `BOARD_PIN_SDI12_RX_EN` | 9 | Left asserted permanently (always listening) |
| `BOARD_PIN_SDI12_BUS_POWER` | 43 | `12V_EN` |
| `BOARD_PIN_RS485_TX_EN`/`RX_EN` | 18 / 8 | Held **low** by `sdi12_bus_init()` — shares the same `SER_TX`/`SER_RX` trunk, must stay disabled while SDI-12 is active |
| `BOARD_PIN_RS232_TX_EN`/`RX_EN` | 17 / 16 | Same reasoning as RS485 |
| `BOARD_PIN_I2C_SDA` / `SCL` | 42 / 2 | |
| `BOARD_PIN_I2C_BUS_POWER` | 1 | `I2C_BUSPOW` |
| `BOARD_PIN_SD_CLK`/`CMD`/`D0` | 5 / 6 / 4 | SDMMC **1-bit** mode — no D1-D3 wired |
| `BOARD_PIN_SD_CARD_DETECT` | *unset* | Not visible on the schematic pages available; SD works fine without it |
| `BOARD_PIN_STATUS_LED` | *unset* | Optional; GPIO38/39 (`GPIOA`/`GPIOB`) are spare header pins if you wire one up |
| `BOARD_PIN_FORCE_AP_BUTTON` | *unset* | Optional; extension point for `net_manager_force_ap_on()` |

Two things are **inferred, not confirmed**: the SDI-12 enable pins'
active level (assumed active-HIGH, since the SN74LV1T126 buffer chip only
supports active-high OE — there's no other option for that specific part),
and the SD card's electrical polarity/timing margins (standard SDMMC, not
board-specific). If SDI-12 doesn't work, check enable-pin polarity with a
meter before assuming the driver logic is wrong.

**The safety pattern**: every subsystem's init function calls
`board_pin_is_set(pin)` (`pin != GPIO_NUM_NC`) on the pins it needs and
returns an error — logged, not fatal — rather than ever driving an
unconfirmed pin. This is why you can build and flash today even with some
pins still unset; only the affected subsystem stays disabled.

---

## 9. Sensor buses

### 9.1 SDI-12 (`sdi12_bus`)

SDI-12 is a 1200-baud, 7-data-bit, even-parity, 1-stop-bit serial protocol
with **inverted mark/space polarity** versus standard UART (idle/mark =
logic LOW, break/space = logic HIGH) and a non-standard wake sequence (a
≥12ms break, then a ≥8.33ms marking gap, before the actual command).

**Why bit-banged instead of hardware UART or RMT**: early design
considered both. Hardware UART was ruled out initially under the wrong
assumption that SDI-12 shared one bidirectional GPIO (a real UART peripheral
can't easily do open-drain half-duplex on a single pin without extra
GPIO-matrix trickery) — though the schematic later revealed Walter Feels
actually *does* wire SDI-12 through separate TX/RX pins onto a shared UART
trunk, which in hindsight could support a hardware-UART implementation.
RMT (ESP32's dedicated pulse-train peripheral) was considered but rejected
in favor of something easier to reason about and verify without hardware
access: **manual GPIO bit-banging**, using a GPIO interrupt to detect each
character's start-bit edge (avoiding a busy-wait across the sensor's
up-to-750ms response gap) plus a short `esp_rom_delay_us` busy-wait to
sample that one character's bits at their centers.

Key constants (`sdi12_bus.c`): `SDI12_BIT_PERIOD_US = 833` (1/1200s),
`SDI12_BREAK_US = 15000`, `SDI12_MARKING_US = 9000` (both padded above the
spec minimums).

Concurrency: `sdi12_bus_init()` configures `BOARD_PIN_SDI12_TXD` as a
permanent output and `BOARD_PIN_SDI12_RXD` as a permanent input with a GPIO
interrupt (only enabled during an active receive wait) — no
`gpio_set_direction()` toggling needed at transaction time, since TX and RX
are physically separate pins. An internal mutex (`sdi12_bus.c`) serializes
whichever task calls in (`sdi12_sched`, or the web portal's preview/scan
handlers from the HTTP task).

**API** (`include/sdi12_bus.h`):

```c
esp_err_t sdi12_bus_init(void);
esp_err_t sdi12_send_command(char addr, const char *cmd_body,
                              char *resp_buf, size_t resp_buf_len,
                              uint32_t response_timeout_ms);
esp_err_t sdi12_scan_addresses(char *found, size_t max_found, size_t *out_count);
esp_err_t sdi12_change_address(char old_addr, char new_addr);
esp_err_t sdi12_measure_and_read(char addr, uint8_t parameter_index, double *out_value);
esp_err_t sdi12_variable_read(const variable_config_t *var, double *out_value); // sensor_bus_read_fn_t adapter
```

`sdi12_measure_and_read()` implements the standard `aM!` → wait → `aD0!`
sequence and parses concatenated signed-decimal values (SDI-12 has no
delimiter between values; `strtod()`'s end-pointer naturally lands on the
next value's sign character, so repeated `strtod()` calls split them
cleanly). **Known limitation**: it only issues `aD0!`, not `aD1!..aD9!`, so
sensors returning more values than fit in one `aD0!` response aren't fully
supported yet — see `sdi12_protocol.c`.

**Status**: pin assignments are confirmed from the schematic; the bit
timing and enable-pin polarity are not yet verified against real hardware
(no oscilloscope/sensor was available while writing this).

### 9.2 I2C (`i2c_bus` + `i2c_sensors`)

`i2c_bus` wraps ESP-IDF's `driver/i2c_master.h` (the modern handle-based
API, not the legacy `driver/i2c.h`). Because that API requires an explicit
per-address "device" handle before you can transact, `i2c_bus` keeps a
small cache (`MAX_CACHED_DEVICES = 16`) mapping address → handle,
created lazily on first use. Same ownership/mutex pattern as `sdi12_bus`.

> **This whole bus needs battery/PV power, not just USB.** Confirmed by
> the board owner: the bus (and every device on it) is fed from "Feels
> 5V", a rail derived from the battery/PV input - USB alone can't power
> it. Bench-testing over USB only, no battery connected, will reliably
> print `i2c_bus`'s boot-time "I2C bus stuck (SDA held low)" / "recovery
> failed" warnings - that's expected (the bus is genuinely unpowered,
> not wedged), not a firmware bug. See `board_pins.h`'s
> `BOARD_PIN_I2C_BUS_POWER` comment.

```c
esp_err_t i2c_bus_init(void);
esp_err_t i2c_bus_write(uint8_t addr7, const uint8_t *wbuf, size_t wlen, uint32_t timeout_ms);
esp_err_t i2c_bus_write_read(uint8_t addr7, const uint8_t *wbuf, size_t wlen,
                              uint8_t *rbuf, size_t rlen, uint32_t timeout_ms);
esp_err_t i2c_bus_scan(uint8_t *found, size_t max_found, size_t *out_count); // via i2c_master_probe
```

`i2c_sensors` is a small **device-type registry** (`i2c_sensor_registry.h`)
dispatching on `variable_config_t.addr.i2c.device_type`:

| Constant | Value | Driver |
|---|---|---|
| `I2C_DEVICE_TYPE_ADS111X` | 0 | TI ADS1113/1114/1115, 16-bit ADC |
| `I2C_DEVICE_TYPE_GENERIC_REG16` | 1 | Raw signed 16-bit big-endian register read, no scaling |
| `I2C_DEVICE_TYPE_HDC1080_TEMP` | 2 | TI HDC1080 temperature, fixed addr 0x40 |
| `I2C_DEVICE_TYPE_HDC1080_HUMIDITY` | 3 | TI HDC1080 humidity, fixed addr 0x40 |
| `I2C_DEVICE_TYPE_LPS22HB_PRESSURE` | 4 | ST LPS22HB pressure, addr 0x5C/0x5D |
| `I2C_DEVICE_TYPE_LPS22HB_TEMP` | 5 | ST LPS22HB temperature, addr 0x5C/0x5D |
| `I2C_DEVICE_TYPE_LTC4015` | 6 | Battery charger/monitor telemetry, fixed addr 0x68 |

**All of the above go through `i2c_bus` (the external connector bus)**,
including HDC1080/LPS22HB despite `board_pins.h` having a separate
`onboard_i2c_bus`/`BOARD_PIN_ONBOARD_I2C_*` bus that their naming might
suggest. That separate bus (GPIO12/11, schematic-labeled `CO2_SDA`/
`CO2_SCL`) is reserved for the optional, currently-unpopulated CO2
(SCD30) + LSM6DSM IMU header - real-hardware I2C scan evidence (see
`board_pins.h`'s comment on `BOARD_PIN_ONBOARD_I2C_SDA`) corrected an
earlier assumption that HDC1080/LPS22HB lived there instead.

`ads111x_read_channel()` uses a fixed configuration — PGA ±4.096V
full-scale, single-shot mode, 128SPS (`ADS111X_CONVERSION_DELAY_MS = 10`
padding above the ~7.8ms conversion time) — and returns a **voltage in
volts** (`raw / 32768.0 * 4.096`). See [section 20.1](#201-adding-a-new-i2c-sensor-driver)
for how to add another device type.

---

## 10. Sampling and aggregation (`sampling_engine`)

Two scheduling tasks (`sdi12_sched`, `i2c_sched`), one per `bus_type_t`,
wake every `SCHEDULER_TICK_MS = 200`, re-read the variable list from
`config_store`, and — for each enabled variable whose `sample_interval_ms`
has elapsed — call the bus type's registered `sensor_bus_read_fn_t` and
push the result onto a shared `sample_queue`.

`aggregation_task` drains that queue, folding each sample into a per-
variable **Welford accumulator** (`aggregator.c`) — numerically stable
running mean/variance, updated incrementally rather than by re-summing a
buffer of raw samples. When a variable's `log_interval_ms` elapses, the
accumulator is finalized into an `aggregate_result_t` (raw/mean/min/max/
stddev, `sample_count`, timestamp + `time_is_synced` flag) and fanned out
to every registered sink (see [6.2](#62-fan-out-via-result-sinks)), then
reset.

Both scheduling tasks and the aggregation task rebuild their internal
schedule/accumulator tables whenever they observe `config_store`'s
generation counter change (see [7.3](#73-the-generation-counter-pattern)),
so adding/editing/deleting a variable via the portal takes effect within
one scheduling tick — no reboot.

`sampling_engine_read_once(variable_id, &value)` is the synchronous,
one-shot path used by the web portal's Preview button — it bypasses
aggregation entirely and calls straight through to the registered driver.

Registering a driver:

```c
typedef esp_err_t (*sensor_bus_read_fn_t)(const variable_config_t *var, double *out_value);
void sampling_engine_register_bus_driver(bus_type_t bus_type, sensor_bus_read_fn_t read_fn);
```

`app_main.c` registers `sdi12_variable_read`/`i2c_variable_read` on
success, or `stub_sensor_read` (a synthetic sine-wave-plus-noise source,
`components/stub_sensor/`) as a fallback — useful for exercising the whole
sample→aggregate→sink pipeline without any real hardware attached.

---

## 11. SD logging (`sd_logger`)

Mounts the microSD card via `esp_vfs_fat_sdmmc_mount()` in **1-bit SDMMC
mode** (`slot_cfg.width = 1`, pins from `board_pins.h`) — not SPI, despite
that being the more common carrier-board wiring; this board's schematic
uses SDMMC signal names (`SD_CMD`/`SD_CLK`/`SD_DATA0`).

Two independent, day-bucketed CSV file series under `/sdcard/data/`:

- `sensors_...csv` — sensor readings, shape controlled by
  `sd_settings_t.log_format` (`/api/settings/sd`, see below), fed by a
  queue (`RESULT_QUEUE_LEN = 32`) that's what `sd_logger_get_sink_queue()`
  hands to `sampling_engine_add_result_sink()`.
- `position_YYYYMMDD.csv` — one row per GNSS fix, fed by a second, smaller
  queue (`POSITION_QUEUE_LEN = 4`) via `sd_logger_log_position()`. Always
  the original long-style layout regardless of `log_format` - a single
  fixed-schema record type, not per-variable/aggregate data.

Both are serviced by the same `sd_writer_task` (all file I/O confined to
one task), which drains the sensor queue with a bounded wait
(`pdMS_TO_TICKS(5000)`, for periodic watchdog resets), then calls
`check_group_timeouts()` (see below) and non-blockingly drains any
pending position rows, each iteration.

Filenames use UTC via `gmtime_r`; unsynced timestamps (before SNTP/cellular
time sync) land in `*_19700101.csv` — a deliberate, well-defined bucket
rather than special-cased handling.

Card-absent/write-failure resilience: `write_result_row()`/
`write_position_row()`/`flush_group_row()` just log an error and increment
`s_drop_count` (exposed via `sd_logger_get_drop_count()`, surfaced in
`/api/status`) rather than blocking or crashing.

### 11.1 `sd_log_format_t`: LONG vs. WIDE_SIMPLE vs. WIDE_TOA5

`SD_LOG_FORMAT_LONG` (default) is the original per-event-row layout,
`sensors_YYYYMMDD.csv`, one row per finalized `aggregate_result_t` -
`write_result_row()`, unchanged.

`SD_LOG_FORMAT_WIDE_SIMPLE`/`SD_LOG_FORMAT_WIDE_TOA5` write one row per
"scan" instead - one column per variable+aggregate, grouped into a
separate file per distinct `log_interval_ms` (mirroring how a Campbell
Scientific datalogger writes a separate output table per scan rate).
This needs actual row-assembly logic, since `aggregate_result_t`s for
different variables arrive independently on the same queue, whenever
each variable's own aggregation cycle in `sampling_engine.c` completes:

- `rebuild_groups_if_needed()` polls `config_store_get_generation()`
  (same pattern as `sampling_engine`'s scheduler/aggregation tasks) and
  regroups all enabled variables by `log_interval_ms` into
  `s_groups[MAX_INTERVAL_GROUPS]`, flushing any in-flight pending rows
  first so membership never changes out from under a row being
  assembled.
- `handle_wide_result()` files an incoming result into its group's
  pending row. A variable reporting again while its own slot is already
  filled means a new scan has started, so the (possibly incomplete)
  pending row is flushed before starting the next one - this keeps
  logging live even if one sensor in a group is permanently missing,
  rather than waiting forever for a slot that will never fill.
  Independently, `check_group_timeouts()` force-flushes any pending row
  older than `log_interval_ms + GROUP_TIMEOUT_GRACE_MS` (5s), covering
  the case where a group's *only* member (or the specific member that
  would otherwise trigger the "reporting again" flush) stops reporting.
  A variable's blank cell in the flushed row means it didn't make it in
  time for that particular scan.
- File naming embeds an FNV-1a hash (`build_column_signature()`/
  `fnv1a()`) of the group's exact column set (variable names, units,
  aggregate masks) into the filename
  (`sensors_iv<interval>_<hash>_YYYYMMDD.csv`). If a config edit changes
  a group's columns mid-day, the hash changes and logging transparently
  rolls onto a new file instead of corrupting an existing file's column
  alignment - no need to read back and diff any existing file's header.
- `write_group_header()`/`write_group_data_row()` branch on
  `log_format` for the two wide variants: `WIDE_SIMPLE` writes a single
  `# station_name=...,device_id=...,interval_ms=...` comment line plus
  one column-name header row (names baked in as
  `<name>_<agg>[_<unit>]`, sanitized via `sanitize_csv_token()` since
  student-chosen names/units aren't guaranteed comma/quote-free);
  `WIDE_TOA5` writes real TOA5's 4-line header (file-info, quoted field
  names, units, aggregate-type-per-column using TOA5's own
  Avg/Max/Min/Std/Smp vocabulary - see `AGG_COLUMNS[]`) and formats
  `TIMESTAMP` as a quoted `"YYYY-MM-DD HH:MM:SS"` string rather than a
  raw unix timestamp, matching real TOA5 exports.
- `sd_settings_t` (`station_name`, `log_format`) lives in
  `device_config_t.sd`, same getter/setter/REST (`/api/settings/sd`)
  pattern as `battery_settings_t`/`position_settings_t`.

---

## 12. Networking (`net_manager`)

### 12.1 Always-on SoftAP policy

`ap_policy.c` is a small state machine, independent of the data-plane
transport:

```
        boot
         │
         ▼
  ┌─────────────┐  AP_BOOT_GRACE_MS elapses, 0 clients   ┌────────┐
  │ BOOT_GRACE  │ ───────────────────────────────────────▶│ AP_OFF │
  │ (AP forced  │                                          └───┬────┘
  │  on, 5 min) │  AP_BOOT_GRACE_MS elapses, ≥1 client         │ client
  └──────┬──────┘ ────────────┐                                │ connects
         │                     ▼                                │
         │ client connects  ┌──────────────────┐◀───────────────┘
         │ (no transition,  │ AP_ACTIVE_BY_    │
         │  just counts)    │ CLIENT           │
         └─────────────────▶│ (on while ≥1     │
                             │  client present) │
                             └────────┬─────────┘
                                      │ last client disconnects
                                      ▼
                                  AP_OFF
```

`AP_BOOT_GRACE_MS = 5 * 60 * 1000` (5 minutes). Client count is tracked via
`WIFI_EVENT_AP_STACONNECTED`/`AP_STADISCONNECTED`. `net_manager.c`'s
`apply_wifi_mode_for_ap_state()` callback translates AP-policy state
changes into actual `esp_wifi_set_mode()` calls, combined with whether STA
is also wanted (`compute_desired_mode()` picks `WIFI_MODE_NULL` / `_AP` /
`_STA` / `_APSTA`). `net_manager_force_ap_on()` is an unused-today
extension point for a future physical button
(`BOARD_PIN_FORCE_AP_BUTTON`).

The AP SSID is `WalterSensor-XXYY` (last two MAC bytes, uppercase hex),
**open** (`WIFI_AUTH_OPEN` — no WiFi password; the portal's own login is
the security boundary), channel 1, max 4 simultaneous stations.

### 12.2 WiFi station mode

Only configured/started when `net_settings.transport == TRANSPORT_WIFI`.
Connects on `WIFI_EVENT_STA_START`, retries on `WIFI_EVENT_STA_DISCONNECTED`
with a fixed `STA_RECONNECT_DELAY_US = 5,000,000` (5s) backoff via a
one-shot `esp_timer` (not a busy-loop), and tracks connected state via
`IP_EVENT_STA_GOT_IP` for `net_manager_sta_is_connected()`.

### 12.3 Captive portal DNS

`web_portal`'s `dns_hijack.c` runs a UDP:53 listener that answers every DNS
query with the AP's own IP (192.168.4.1) — the standard trick that makes
phones/laptops auto-open the login page. It's started unconditionally at
`web_portal_init()` and is harmless when the AP is off (no clients means no
queries reach it).

---

## 13. MQTT (`mqtt_client`)

### 13.1 Dual-backend abstraction

`mqtt_backend.h` defines a small vtable so the rest of the app never
touches a transport-specific MQTT implementation directly:

```c
typedef struct {
    esp_err_t (*init)(const mqtt_settings_t *cfg);
    esp_err_t (*connect)(void);
    esp_err_t (*disconnect)(void);
    esp_err_t (*publish)(const char *topic, const char *payload, int qos, bool retain);
    bool      (*is_connected)(void);
    esp_err_t (*deinit)(void);
} mqttc_backend_vtable_t;
```

`mqttc_init()` selects a backend **once**, based on `net_settings.transport`
at boot (matching the "transport requires a reboot" design decision):
`backend_esp_mqtt.c` (wraps ESP-IDF's `esp-mqtt` over WiFi/lwIP/esp-tls) for
`TRANSPORT_WIFI`, `backend_walter_mqtt.cpp` (wraps `WalterModem`'s on-modem
MQTT client) for `TRANSPORT_CELLULAR`, or `NULL` (fully inert) otherwise.

### 13.2 Immediate vs. batch publish

`mqtt_publish_task` (`mqtt_client_bridge.c`) branches on
`mqtt_settings.batch_enabled`:

- **Immediate (default, `batch_enabled = false`)**: the backend connects
  once (in `apply_settings_if_changed()`, whenever settings actually
  change) and stays connected; each result is published as it arrives.
- **Batch (`batch_enabled = true`)**: results accumulate in a bounded
  buffer (`s_batch_buffer[MAX_BATCH_ITEMS]`, `MAX_BATCH_ITEMS = 256`)
  instead of being published. Once `esp_timer_get_time() >=
  s_next_batch_transmit_us`, the task connects, drains the buffer (and any
  pending position fix — see below), disconnects, and schedules
  `s_next_batch_transmit_us = now + batch_interval_ms`. Enabling batching
  or changing the interval resets the schedule to "now" so the first
  transmission isn't delayed a full interval.

Buffer overflow drops the newest sample (logged) — SD logging is
unaffected either way, since it's a separate sink fed independently by
`sampling_engine`.

### 13.3 Topics and payloads

`publish_result()` builds `<topic_prefix>/<device_id>/<sanitized_name>`
(`sanitize_topic_segment()` replaces `/`, `+`, `#` with `_`, since those
are reserved MQTT topic-level characters). Payload is JSON with `ts`,
`time_synced`, `n` (sample count) always present, plus one field per
aggregate the variable's `aggregate_mask` actually selected: `raw`, `mean`,
`min`, `max`, `stddev`.

`mqttc_publish_position()` (called by `gnss_position`) stores only the
*latest* pending fix (overwriting any not-yet-sent previous one, under
`s_position_mutex`) and is drained by `mqtt_publish_task` alongside regular
samples — so a position fix rides along with the next batch window rather
than opening a second connection. Topic:
`<topic_prefix>/<device_id>/position`, payload `{ts, time_synced, lat, lon,
alt}`.

### 13.4 `backend_esp_mqtt.c`

Uses the documented stable esp-mqtt API (`broker.address.uri`,
`credentials.*`, `broker.verification.crt_bundle_attach` for TLS, or
`skip_cert_common_name_check` for the lab-friendly insecure-TLS toggle).
Not verified against local source in this checkout — see
[section 18](#18-known-limitations-and-low-confidence-areas).

---

## 14. Cellular integration (`cellular_transport`)

Wraps DPTechnics' `dptechnics/walter-modem` C++ library. Because there's
exactly one physical modem, a single `WalterModem` instance is shared
between `cellular_transport.cpp` and `mqtt_client`'s
`backend_walter_mqtt.cpp` via a Meyer's-singleton accessor in a **C++-only**
private header (`cellular_transport_cpp.h` — deliberately not included from
any `.c` file, since `WalterModem` is a C++ type):

```cpp
WalterModem &cellular_transport_get_modem();
```

The public, C-callable API (`cellular_transport.h`) covers registration
status, PDP context state, and GNSS:

```c
esp_err_t cellular_transport_init(void);          // begin() + PDP context activation
bool      cellular_transport_is_registered(void);
bool      cellular_transport_is_pdp_active(void);

esp_err_t cellular_transport_acquire_gnss_fix(gnss_fix_t *out_fix, uint32_t timeout_ms);
void      cellular_transport_get_last_fix(gnss_fix_t *out_fix);
```

`cellular_task` polls registration state every 5 seconds.
`cellular_transport_init()` is only ever called when `net_settings.transport
== TRANSPORT_CELLULAR`.

**⚠️ This entire component is the lowest-confidence part of the firmware.**
`dptechnics/walter-modem` is fetched from the ESP Component Registry at
build time and was never present in the checkout this was developed
against, so no method signature here was checked against a real header —
every WalterModem call (`begin()`, `definePDPContext()`,
`getNetworkRegState()`, `gnssPerformFix()`, and MQTT-related calls in
`backend_walter_mqtt.cpp`) is a best-effort guess from a research summary,
marked `VERIFY` inline. Treat this component as an architectural skeleton
to correct against the real `WalterModem.h` once fetched
(`managed_components/dptechnics__walter-modem/src/WalterModem.h`), not as
tested code.

---

## 15. Position reporting (`gnss_position`)

A single task, spawned only when `net_settings.transport ==
TRANSPORT_CELLULAR` (`gnss_position_init()` is a no-op otherwise — no task
spawned at all).

`position_settings_t` deliberately mirrors `variable_config_t`'s
sample/log-interval + `aggregate_mask` shape (`config_schema.h`) — GPS
position is conceptually a variable with four fields (latitude, longitude,
elevation, horizontal precision) rather than one, kept as its own
config/UI section instead of joining the generic `variables[]` array since
it's device-wide, not per-sensor, and keeps its own dedicated CSV file /
MQTT payload shape rather than becoming four generic variables. Each
field gets its own `aggregator_t` (`sampling_engine`'s `aggregator.h` -
the exact same Welford accumulator `sampling_engine.c` itself uses, just
driven locally here rather than through the generic bus-driver path).
Each cycle:

1. Read `position_settings_t` from `config_store` (checked fresh every
   cycle, so toggling it on/off or changing the intervals/aggregates
   doesn't need a reboot, unlike `transport` itself).
2. If disabled (or either interval is 0), reset all four accumulators and
   sleep `IDLE_CHECK_MS = 5000` before rechecking.
3. If enabled, call `cellular_transport_acquire_gnss_fix()` (up to
   `GNSS_FIX_TIMEOUT_MS = 60000`); on success, feed
   latitude/longitude/altitude/`horizontal_accuracy_m` into their
   accumulators (starting a new log window's deadline on the first
   sample, not on a fixed clock schedule) and set the modem-derived
   timestamp as this window's own. Once `log_interval_ms` has elapsed
   since the window opened, finalize all four accumulators into
   `field_aggregate_t`s, call `sd_logger_log_position()` and
   `mqttc_publish_position()` with the bundle, then reset. Either way,
   sleep `sample_interval_ms` before the next fix attempt.

`gnss_fix_t.horizontal_accuracy_m` (`cellular_transport.h`) is
WalterModem's own `estimatedConfidence` - "the estimated horizontal
confidence of the fix in meters" per its header comment; not independently
verified beyond that, same confidence caveat as the rest of this
component (see [section 18](#18-known-limitations-and-low-confidence-areas)).

Requires a physical GNSS antenna connected to the modem - without one,
`gnssPerformAction()` just fails/times out repeatedly rather than ever
producing a fix. Firmware has no way to detect antenna presence itself;
the portal surfaces this as a plain warning instead (`index.html`'s
`positionFormFields()`).

Not registered with the task watchdog — see
[6.3](#63-task-watchdog-registration).

---

## 16. Device identification (`device_id`)

A tiny, dependency-light component: `device_id_get()` reads the ESP32's
factory-programmed MAC (`esp_read_mac(mac, ESP_MAC_WIFI_STA)`) once, caches
it as a 12-character uppercase hex string (`"AABBCCDDEEFF"`), and returns
the cached pointer on every subsequent call. Used by `sd_logger` (CSV file
header line), `mqtt_client` (topic segment), `web_portal` (`/api/status`),
and logged in the boot banner.

---

## 17. Web portal (`web_portal`)

### 17.1 Structure

```
web_portal/
├── web_portal.c            # httpd_start(), route registration order, SPA catch-all
├── web_portal_internal.h   # private helpers shared across this component's .c files
├── wp_common.c             # JSON response/request helpers, URI id parsing
├── auth.c                  # session table, login/logout, wp_auth_require()
├── dns_hijack.c            # UDP:53 captive-portal DNS responder
├── api_variables.c         # /api/variables CRUD + preview
├── api_settings.c          # /api/settings/* (mqtt, network, position, password, export/import), /api/system/reboot
├── api_status.c            # /api/status
├── api_bus.c                # /api/bus/{sdi12,i2c}/scan
└── assets/index.html       # the entire SPA - embedded into the firmware image
```

### 17.2 Route matching order matters

`esp_http_server` matches registered URI handlers **in registration
order**, first match wins (confirmed from `httpd_find_uri_handler()` in
ESP-IDF source — it's a linear scan, not sorted by specificity). All
`/api/*` routes are registered before the wildcard `GET /*` catch-all that
serves the embedded SPA for anything unmatched — including the OS-specific
captive-portal probe paths (`/generate_204`, `/hotspot-detect.html`,
`ncsi.txt`, ...), since serving the SPA body (rather than each OS's
expected "no portal here" response) is what triggers the captive-browser
popup.

### 17.3 Authentication

Login page + server-side session, not HTTP Basic (avoids retransmitting the
password on every request, and the ugly native browser auth dialog).
`POST /api/login` verifies against the salted SHA-256 hash in
`config_store`, issues a random 16-byte hex token as an `HttpOnly` cookie
named `session` (`Max-Age=1800`). Sessions are a fixed array
(`MAX_SESSIONS = 4`), each with a sliding `SESSION_IDLE_TIMEOUT_US = 30 *
60 * 1000000` (30 min) refreshed on every authenticated request; when all
slots are full, the soonest-to-expire is evicted. Every `/api/*` handler
except `/api/login` calls `wp_auth_require(req)` first, which sends the 401
response itself on failure so the handler can just `return ESP_OK`.

### 17.4 Full REST API reference

All routes except `/api/login` require a valid session cookie.

| Method | Path | Body | Notes |
|---|---|---|---|
| POST | `/api/login` | `{password}` | Sets the session cookie |
| POST | `/api/logout` | — | Clears the session |
| GET | `/api/status` | — | See [section 17.5](#175-status-response-fields) |
| GET | `/api/variables` | — | Array of variables |
| POST | `/api/variables` | variable object (no `id`) | Returns `{id}` |
| PUT | `/api/variables/{id}` | variable object | |
| DELETE | `/api/variables/{id}` | — | |
| POST | `/api/variables/{id}/preview` | — | One-shot read via `sampling_engine_read_once()`, returns `{value}` |
| GET | `/api/bus/sdi12/scan` | — | Array of responding address chars; can take several seconds |
| GET | `/api/bus/i2c/scan` | — | Array of responding 7-bit addresses (numbers) |
| GET/PUT | `/api/settings/mqtt` | `mqtt_settings_t`-shaped JSON | `password` is write-only (never echoed; a `password_set` bool is returned instead) |
| GET/PUT | `/api/settings/network` | `net_settings_t`-shaped JSON | Changing `transport` returns `reboot_required: true` |
| GET/PUT | `/api/settings/position` | `{enabled, interval_ms}` | GET also includes an `available` bool (`transport == cellular`) |
| PUT | `/api/settings/password` | `{old, new}` | `new` must be ≥4 chars |
| GET | `/api/settings/export` | — | Full config JSON, secrets redacted (`portal_password_hash` omitted; `mqtt.password`/`wifi_sta_password`/`cellular_pin` blanked) |
| POST | `/api/settings/import` | Full config JSON | Preserves current secrets for any field left blank/omitted, rather than wiping them |
| POST | `/api/system/reboot` | — | Responds first, then `esp_restart()` after a 500ms `esp_timer` delay |

Variable JSON shape (`config_store_variable_to_json`/`_from_json`):

```json
{
  "id": 1, "name": "soil_temp", "bus_type": 0,
  "addr": {"address": "0", "parameter_index": 0},
  "unit": "degC", "sample_interval_ms": 60000, "log_interval_ms": 300000,
  "aggregate_mask": 3, "calibration_a": 1.0, "calibration_b": 0.0, "enabled": true
}
```

`bus_type`: `0` = SDI-12 (`addr` = `{address, parameter_index}`), `1` = I2C
(`addr` = `{i2c_addr, device_type, channel_index, gain}` - `gain` only
meaningful for `device_type` `I2C_DEVICE_TYPE_ADS111X`). `aggregate_mask` is a
bitmask: `RAW=1, MEAN=2, MIN=4, MAX=8, STDDEV=16` — e.g. `3` = raw + mean.
`calibration_a`/`calibration_b` apply `calibrated = a * raw + b` to every
sample before it reaches the aggregator (see `sampling_engine.c`'s
`bus_scheduler_task` and `sampling_engine_read_once`) - defaults `(1.0, 0.0)`
are a no-op.

### 17.5 Status response fields

`GET /api/status` (see `api_status.c`):

`device_id`, `uptime_s`, `free_heap_bytes`, `ap_active`, `ap_client_count`,
`transport` (`"unconfigured"`/`"wifi"`/`"cellular"`), `data_connection_up`,
`time_synced`, `time_unix`, `sd_ready`, `sd_total_bytes`, `sd_free_bytes`,
`sd_drop_count`, `mqtt_enabled`, `mqtt_batch_enabled`, `mqtt_connected`,
`position_enabled`, `position_available` — plus, only when
`transport == "cellular"`: `position_fix_valid` and (if valid)
`position_latitude`/`position_longitude`/`position_altitude_m`/
`position_timestamp_unix` — and finally `variable_count`,
`config_generation`.

### 17.6 The SPA

`assets/index.html` is a single self-contained file (inline `<style>` and
`<script>`, no build step, no framework) embedded into the firmware binary
via CMake's `EMBED_FILES` (symbol name derived from the file's *basename*
only, regardless of subdirectory — `_binary_index_html_start`/`_end`).
This was a deliberate simplicity choice given no OTA/no runtime-asset-
update requirement in v1; revisit with a LittleFS asset partition only if
the SPA outgrows embedding in the firmware image.

---

## 18. Known limitations and low-confidence areas

Ranked roughly by how much you should distrust them before relying on
them in a real deployment:

1. **`cellular_transport` and `mqtt_client/backend_walter_mqtt.cpp`**
   (lowest confidence) — every `WalterModem` call is an unverified guess.
   See [section 14](#14-cellular-integration-cellular_transport).
2. **`sdi12_bus`** — pin numbers are confirmed from the schematic, but bit
   timing and enable-pin polarity are not verified against real hardware.
3. **`mqtt_client/backend_esp_mqtt.c`** — written against documented
   stable esp-mqtt API shape, but this checkout's ESP-IDF was missing the
   `mqtt/esp-mqtt` submodule source, so it couldn't be checked against a
   real header either.
4. **`sdi12_measure_and_read()`** only issues `aD0!`, not `aD1!..aD9!` — a
   known, intentional v1 limitation for sensors returning many values.
5. **`board_pins.h`**: SD card-detect, status LED, and force-AP-button
   pins are still unset placeholders (nothing on the available schematic
   pages showed them).
6. ~~HDC1080/LPS22HB bus location~~ — **resolved**, no longer a limitation.
   Corrected from an earlier wrong assumption (they were originally wired
   through `onboard_i2c_bus`, not `i2c_bus`): real-hardware I2C scan
   evidence found their addresses (plus LTC4015 and an LSM6DSM IMU) all on
   the external bus, and the board owner confirmed directly that every I2C
   device on this board (GPIO42/2/1) shares one bus - `onboard_i2c_bus`
   (GPIO12/11/13) only reaches a real but currently-unpopulated CO2 sensor
   header. See [section 9.2](#92-i2c-i2c_bus-i2c_sensors).
7. **No OTA** — reflashing requires physical USB access.
8. **MQTT batch buffer** (`MAX_BATCH_ITEMS = 256`) can overflow (drops
   silently, logged) if you combine many variables, short log intervals,
   and a long batch interval — see the sizing note in
   [USER_MANUAL.md §7.4](USER_MANUAL.md#74-batch-transmission-saving-power).
9. **Automatic light sleep (`CONFIG_PM_ENABLE`) is off, deliberately.**
   Confirmed on real hardware to cause a permanent boot hang right after
   "sampling engine started" — reproduced with every other variable ruled
   out (see `sdkconfig.defaults`'s own comment on these two options for
   the full bisection). Leading suspect is `sd_logger_init()`'s SDMMC
   mount attempt (the first real timing-sensitive hardware wait after
   that log line) not being light-sleep-safe, but the exact internal
   mechanism isn't independently verified, only the correlation. Don't
   re-enable `CONFIG_PM_ENABLE`/`CONFIG_FREERTOS_USE_TICKLESS_IDLE`
   without hardware in hand to test against.

---

## 19. Testing without Walter Feels hardware

If you don't have a Walter/Walter Feels board yet, you can still exercise
the sensor pipeline, the config store, and the web portal end-to-end on a
plain **ESP32 DevKit V1** wired to one or more I2C sensors (e.g. two
ADS1115 ADC boards) — SDI-12, SD card, and cellular are simply left
disabled, exactly like they would be on real hardware with those pins
unset (see [section 8](#8-board-pin-mapping-board_pins)).

### 19.1 Why this needs more than flashing the same firmware

Two things differ, not just the board_pins.h values:

- **Chip target**: the DevKit V1 uses a classic **ESP32** (Xtensa LX6),
  not the **ESP32-S3** the rest of this project targets. Some existing
  `board_pins.h` GPIO numbers (e.g. 40-43) don't even exist on classic
  ESP32, and the S3-specific octal-PSRAM/USB-Serial-JTAG sdkconfig
  settings don't apply either.
- **Pin mapping**: Walter Feels' SDI-12/I2C/SD pins are meaningless on a
  bare DevKit — there's no SN74LV1T126 buffer, no SDMMC wiring, nothing.

Both are handled by two independent switches you set together:

| Switch | How | Affects |
|---|---|---|
| Chip target | `idf.py set-target esp32` | Which `sdkconfig.defaults.<target>` file gets merged (`sdkconfig.defaults.esp32` vs. `sdkconfig.defaults.esp32s3`) — flash size, PSRAM, console. |
| Board variant | `idf.py menuconfig` → "Walter Sensor Node Board Selection" → "Generic ESP32 DevKit V1" (`CONFIG_BOARD_VARIANT_ESP32_DEVKIT_TEST`) | Which `#if` branch of `board_pins.h` is compiled — see `components/board_pins/Kconfig.projbuild`. |

They're independent settings (nothing stops you from selecting the wrong
combination), but only `esp32` + `ESP32_DEVKIT_TEST` and `esp32s3` +
`WALTER_FEELS` are meaningful pairings.

### 19.2 Step by step

```sh
idf.py set-target esp32
idf.py menuconfig   # Walter Sensor Node Board Selection -> Generic ESP32 DevKit V1
idf.py build
idf.py -p <PORT> flash monitor
```

Wiring, for two ADS1115 boards sharing the bus (I2C requires each device
on a bus to have a distinct address):

- Both boards: `SDA` → GPIO21, `SCL` → GPIO22, `VDD`/`GND` → the DevKit's
  3.3V/GND (see `BOARD_PIN_I2C_SDA`/`BOARD_PIN_I2C_SCL` in `board_pins.h`
  for this variant).
- Give each board a distinct address. On the generic ADS1115 chip
  (TI datasheet), this is done by tying the `ADDR` pin to `GND`→`0x48`,
  `VDD`→`0x49`, `SDA`→`0x4A`, or `SCL`→`0x4B`. Some breakout boards
  instead use their own onboard solder jumpers with a different
  mapping - e.g. Soldered's ADS1115 breakout defaults to `0x48` with no
  jumper closed, and remaps to `0x39`/`0x4A`/`0x4B` via jumpers JP3/JP4/JP5
  respectively (**close only one jumper at a time** - the board's own
  docs warn that closing more than one simultaneously can cause a
  malfunction). Either way, confirm what your specific boards actually
  respond at with the portal's **Scan I2C bus** button rather than
  assuming.

Then in the portal, add one variable per ADC input you want to read: bus
type I2C, the I2C address you found via the scan (in decimal — e.g. `72`
for `0x48`), device type `0` (ADS111x), and pick the input from the
channel dropdown — both single-ended (`AIN0`-`AIN3`) and differential
pairs (`AIN0-AIN1`, `AIN0-AIN3`, `AIN1-AIN3`, `AIN2-AIN3`) are available.
E.g. for differential AIN0-AIN1 and AIN2-AIN3 on each of two boards,
that's four variables total (one per pair per board).

Each variable also has its own **gain / full-scale range** setting
(`+/-6.144V` down to `+/-0.256V`) — pick the smallest range that still
comfortably covers that signal's expected peak, for the best resolution.
Two different variables on the same or different ADS1115 boards can use
different gains (e.g. a 0–5V signal at `+/-6.144V` and a 0–1.5V signal at
`+/-2.048V` on the same chip, on different inputs). **This setting does
not change the chip's absolute maximum input voltage**, which is always
its own supply voltage (`VDD`) + 0.3V regardless of gain — feeding a 0–5V
signal into an ADS1115 powered from the DevKit's 3.3V rail will exceed
that limit no matter what gain is selected; that board needs to be
powered at 5V instead (or the signal scaled down with a divider first).

### 19.3 Component-manager target gating (already handled)

`main/idf_component.yml`'s `dptechnics/walter-modem` dependency is gated
with a component-manager `rules: - if: "target == esp32s3"` clause (that
package only publishes versions for `esp32s3`), and `cellular_transport`'s
`CMakeLists.txt` only adds it to `REQUIRES` `if(CONFIG_IDF_TARGET_ESP32S3)`.
The WalterModem-dependent function bodies in `cellular_transport.cpp` and
`backend_walter_mqtt.cpp` are likewise wrapped in
`#if CONFIG_IDF_TARGET_ESP32S3 ... #else ... #endif`, falling back to
`ESP_ERR_NOT_SUPPORTED` stubs on other targets — so `idf.py set-target esp32`
resolves and builds cleanly without ever touching the modem SDK. This was
confirmed by an actual `esp32` build, not just inferred from the manifest.

---

## 20. How to extend the firmware

### 20.1 Adding a new I2C sensor driver

1. Pick an unused `device_type` number and add a
   `#define I2C_DEVICE_TYPE_<NAME> <n>` to
   `components/i2c_sensors/include/i2c_sensor_registry.h`.
2. Add a new source file, e.g. `components/i2c_sensors/<name>.c`, with a
   function `esp_err_t <name>_read(uint8_t i2c_addr, uint8_t channel, double *out_value)`
   that calls `i2c_bus_write()`/`i2c_bus_write_read()` (see `ads111x.c` for
   the reference shape — register write, delay if needed, register read,
   decode).
3. Declare that function in `i2c_sensor_registry.h` and add a `case` for
   your new `device_type` in `i2c_sensor_read()`
   (`components/i2c_sensors/i2c_sensor_registry.c`).
4. Add the new `.c` file to `components/i2c_sensors/CMakeLists.txt`'s
   `SRCS` list.
5. In the portal, students select your new driver via its numeric
   `device_type` in a variable's I2C settings (no UI changes needed unless
   you want a nicer label — see `assets/index.html`'s `variableFormFields()`
   for where device type is currently a bare number input).

### 20.2 Adding a new REST endpoint

1. Add your handler function to the relevant `api_*.c` file (or create a
   new one, following `api_bus.c` as a minimal example).
2. Register it in that file's `..._register_routes(httpd_handle_t server)`
   function — **register specific routes before any wildcard/catch-all**
   (see [17.2](#172-route-matching-order-matters)).
3. If it's a new file, declare the register function in
   `web_portal_internal.h`, call it from `web_portal.c`'s `web_portal_init()`,
   and add the `.c` file to `components/web_portal/CMakeLists.txt`.
4. Use `wp_auth_require(req)` at the top unless the endpoint is
   intentionally public, and the `wp_send_json`/`wp_send_error`/
   `wp_read_json_body` helpers from `wp_common.c` for consistent response
   shapes.

### 20.3 Adding a new config field

1. Add the field to the appropriate struct in
   `components/config_store/include/config_schema.h`.
2. Set its default in `config_set_defaults()` (`config_store.c`).
3. Add it to both `config_store_to_json()` and the corresponding
   `_from_json()` function for that struct, so NVS persistence and the
   REST API pick it up automatically (they share this code — see
   [7.2](#72-persistence)).
4. If it needs its own GET/PUT exposure, extend the relevant
   `api_settings.c` handler.
5. If a component needs to react to it changing at runtime, read it via
   the generation-counter pattern ([7.3](#73-the-generation-counter-pattern))
   rather than polling `config_store` on every operation.

---

## 21. Glossary

| Term | Meaning |
|---|---|
| ESP-IDF | Espressif's official SDK for ESP32 chips — the framework this firmware is built on (as opposed to the Arduino framework). |
| FreeRTOS | The real-time operating system ESP-IDF runs on; provides tasks, queues, mutexes, semaphores. |
| Task | FreeRTOS's unit of concurrent execution — roughly analogous to a thread. |
| Queue | A FreeRTOS inter-task communication primitive — fixed-size, thread-safe, used throughout this firmware to pass data between tasks without shared-memory races. |
| Mutex / semaphore | Synchronization primitives used to guard shared state accessed from more than one task. |
| NVS | Non-Volatile Storage — ESP-IDF's flash-based key-value store, used here to persist the whole config as one JSON blob. |
| Component | ESP-IDF's unit of modular code — roughly a library, with its own `CMakeLists.txt` declaring sources, public headers, and dependencies (`REQUIRES`). |
| `idf_component.yml` | Declares a managed dependency fetched from the ESP Component Registry at build time (used here for `dptechnics/walter-modem`). |
| GPIO matrix | ESP32's ability to route almost any peripheral signal (UART, SPI, I2C, ...) to almost any physical pin, rather than fixed pin assignments. |
| Task watchdog (TWDT) | ESP-IDF's mechanism to detect a hung task (one that hasn't "checked in" within a timeout) and panic/reboot rather than silently lock up. |
| Welford's algorithm | A numerically stable method for computing running mean/variance incrementally, without needing to store or re-sum all prior samples. |
| PDP context | A cellular data-session concept (from 3GPP) — roughly "the data connection the modem has activated," analogous to a WiFi association + DHCP lease. |
| SoftAP | The ESP32 acting as its own WiFi access point (hotspot), as opposed to "station" (STA) mode, joining someone else's network. |
| Captive portal | The auto-popping "sign in to this network" browser flow triggered by a DNS-hijacking/probe-endpoint trick, used here for first-time setup. |
| cJSON | The C JSON library used throughout this firmware for (de)serialization, both for NVS persistence and the REST API. |
| Vtable (virtual table) | A struct of function pointers used here to let `mqtt_client` swap between two unrelated MQTT implementations (`esp-mqtt` vs. `WalterModem`) behind one interface. |

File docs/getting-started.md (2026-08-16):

# Getting started: solar panel & wind turbine on the Open Renewable Lab

This walkthrough takes you from an unwired RS PRO 20 W solar panel to live
`PV_Voltage` and `PV_Current` readings in ThingsBoard. The Open Renewable
Lab's 100 W vertical-axis wind turbine works exactly the same way — both
sources ship **pre-instrumented** with a load, a resistive voltage divider,
and a current shunt already wired to a 4-pin plug, so there's no sensor
wiring for you to build. The two share the *exact same voltage-divider
design*, so almost every step below applies to both unchanged; the one
real difference is the current shunt (the PV panel uses a 1 Ω shunt, the
turbine a 10 A/75 mV shunt), which changes one calibration number — called
out explicitly in [step 4](#4-preview-and-calibrate) rather than repeated
as a second full walkthrough. This guide uses the solar panel as its
running example; wherever the turbine differs, it says so.

It assumes you're starting from a fresh Open Renewable Lab enclosure (see
[Hardware](hardware.md) for what's inside it) with firmware already
flashed — if not, do [Firmware downloads](firmware-downloads.md) first.

No programming is required for any of this — everything below is either
physical wiring or the device's own web portal, described in full in the
[User Manual](USER_MANUAL.md). This page only covers the parts specific to
an instrumented PV panel or wind turbine; it links to the User Manual for
general portal reference rather than repeating it.

## What you'll need

- An RS PRO 20 W solar panel (or similar small panel), a 100 W
  vertical-axis wind turbine, or both — the steps are the same regardless
  of exact wattage, and an enclosure with both connected just uses one
  analog input per source (see [step 1](#1-how-the-analog-input-works)).
- An Open Renewable Lab enclosure, powered on **with a battery connected
  to BATT**. This isn't optional: the AN1/AN2 analog inputs (and every
  other external I2C device) are powered from a rail derived from the
  battery/PV input, not from USB — running on USB alone, no battery, the
  ADS1115 simply won't be powered and Preview will fail with no obvious
  reason why.
- A multimeter (for the voltage calibration step).
- A phone or laptop with WiFi, to reach the device's setup portal.
- A [ThingsBoard](https://thingsboard.io/) account — either your
  instructor's own instance, or the public
  [demo.thingsboard.io](https://demo.thingsboard.io/) sandbox for testing.

## ⚠ Safety note

Unlike a bench power supply, a solar panel has **no off switch** — any
panel in daylight (even indoor room light will produce a small voltage) is
live the moment it's wired up. Keep the panel covered with an opaque cloth
or bag while making connections, and only uncover it once wiring is
complete and double-checked.

A wind turbine has the same "always live" electrical hazard whenever its
blades are moving (even a light breeze is enough to produce a small
voltage), **plus** a mechanical one — don't work on its wiring while the
blades can spin. Lock/tie the rotor before connecting or disconnecting its
plug, the same way you'd cover the solar panel.

## 1. How the analog input works

⚠ **Not the PV gland.** The enclosure also has a connector labeled **PV**
— that one charges the *logger's own* operating battery from a small
auxiliary panel (straight into the onboard LTC4015 charger), and is
unrelated to measuring your panel or turbine. Your instrumented source
plugs into **AN1** or **AN2** instead (see
[Hardware](hardware.md#connector-reference)) — pick whichever is free; this
guide uses AN1. If you have both a solar panel and a wind turbine wired
into the same enclosure, they just take one analog input each (AN1 for
one, AN2 for the other) — there's no fixed pairing, either input works for
either source.

Each of AN1/AN2 is a generic 4-pin analog input exposing two of the
external ADS1115 ADC's four single-ended channels at I2C address **73**
(`0x49`) — AN1 is `AIN0`/`AIN1`, AN2 is `AIN2`/`AIN3`. The instrumented
source's own 4-pin plug carries both the voltage-divider output and the
current-shunt output, one per channel — the same layout for the solar
panel and the wind turbine, only the shunt's rating (and so the current
calibration in [step 4](#4-preview-and-calibrate)) differs between them:

| Signal | AN1 channel | Circuit | What it measures |
|---|---|---|---|
| PV voltage | `AIN0` | Resistive divider, designed to scale a panel voltage up to roughly the divider's rated ~22 V down to the sensor's ~5 V input range | The panel's terminal voltage |
| PV current | `AIN1` | A 1 Ω 0.5% shunt resistor in the panel's current path | The panel's output current — by design, **1 V measured = 1 A** |
| WT voltage | `AIN0` | The same resistive divider design as the PV panel's, sized for the turbine's own rated output | The turbine's terminal voltage |
| WT current | `AIN1` | A 10 A/75 mV shunt resistor in the turbine's current path (**not** the PV panel's 1 Ω) | The turbine's output current — see [step 4](#4-preview-and-calibrate) for the calibration this shunt needs |

(Using AN2 instead just means `AIN2` for voltage and `AIN3` for current
below — everything else is identical. This also applies per-source: e.g.
solar panel on AN1 and wind turbine on AN2 in the same enclosure means
`AIN0`/`AIN1` for `PV_Voltage`/`PV_Current` and `AIN2`/`AIN3` for
`WT_Voltage`/`WT_Current`.)

## 2. Connect the panel or turbine

1. With the panel covered (or the turbine's rotor locked), plug its
   instrumented 4-pin connector into the enclosure's **AN1** gland (or
   **AN2** — just be consistent with which channels you configure in
   [step 3](#3-add-the-two-variables-in-the-portal)).
2. Double-check the plug is fully seated before uncovering the panel/
   releasing the rotor — a reversed/miswired current path won't damage the
   sensing circuit at this scale, but will show up as a negative reading
   (see [step 4](#4-preview-and-calibrate)).
3. Uncover the panel (or release the rotor) once you're done.

## 3. Add the two variables in the portal

Connect to the device's `WalterSensor-XXXX` hotspot and log in (see
[USER_MANUAL.md §3-4](USER_MANUAL.md#3-quick-start) if this is your first
time). Under **Variables**, add two new I2C variables using the field
reference in [USER_MANUAL.md §6.1](USER_MANUAL.md#61-adding-a-variable):

**PV_Voltage**

| Field | Value |
|---|---|
| Name | `PV_Voltage` |
| Bus type | `I2C` |
| I2C address | `73` |
| Device type | `ADS111x` |
| ADS111x input | `AIN0` |
| Gain / full-scale range | `±6.144V` to start (the divider's designed output tops out around 5 V) |

**PV_Current**

| Field | Value |
|---|---|
| Name | `PV_Current` |
| Bus type | `I2C` |
| I2C address | `73` |
| Device type | `ADS111x` |
| ADS111x input | `AIN1` |
| Gain / full-scale range | `±2.048V` to start (a 20 W-class panel's short-circuit current stays well under 2 A, so under 2 V across a 1 Ω shunt) |

**Using the wind turbine instead (or as well)?** Add `WT_Voltage`/
`WT_Current` the same way — same Bus type/I2C address/Device type, `AIN0`/
`AIN1` (or `AIN2`/`AIN3` on AN2) as above, `±6.144V` for `WT_Voltage`. The
one field that's genuinely different is `WT_Current`'s **Gain /
full-scale range**: its 10 A/75 mV shunt only ever produces up to 75 mV
even at full rated current, so use `±0.256V` (the highest-resolution
range) rather than PV_Current's `±2.048V` — see
[step 4](#4-preview-and-calibrate) for why the shunt difference also
means a different calibration number, not just a different gain.

If the address `73` doesn't respond, use the portal's **Scan I2C bus**
button ([USER_MANUAL.md §6.2](USER_MANUAL.md#62-finding-your-sensors-address))
to confirm what's actually on the bus before assuming a wiring problem.

<figure markdown>
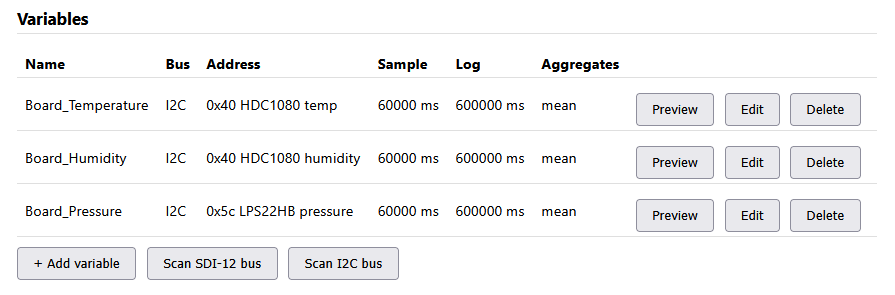
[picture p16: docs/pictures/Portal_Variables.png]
Portal Variables list showing three configured variables

<figcaption>
The Variables list after adding variables — each row shows its bus,
address, sample/log intervals, and aggregates, with Preview/Edit/Delete
per row (this example shows the three onboard environment variables that
ship enabled by default, not PV_Voltage/PV_Current — yours will look the
same shape once you've added those two).
</figcaption>
</figure>

## 4. Preview and calibrate

Leave both variables' calibration at the default (`a=1`, `b=0`) for now,
then click **Preview** on each (see
[USER_MANUAL.md §6.4](USER_MANUAL.md#64-testing-a-sensor-preview)) with the
panel uncovered (or the turbine spinning) in reasonable conditions. The
steps below are written for `PV_Voltage`/`PV_Current` — if you added
`WT_Voltage`/`WT_Current` instead, the *voltage* calibration is identical
(same divider), but the *current* calibration is not (different shunt) —
see the callout at the end of each subsection.

### PV_Current: usually needs no calibration

Because the sensing resistor is a 1 Ω shunt, the raw ADC reading in volts
already **is** the current in amps — `a=1, b=0` is correct as-is, this
isn't a placeholder. If Preview shows a **negative** value, the shunt is
seeing current flow in the direction opposite of what the firmware assumes;
either physically swap the panel's leads, or set `a=-1` in the portal to
flip the sign in software (see
[USER_MANUAL.md §6.6](USER_MANUAL.md#66-calibrating-a-variable-ax-b)).

> **`WT_Current` is different: it needs `a ≈ 133.3`, not `a=1`.** The wind
> turbine's shunt is rated 10 A at 75 mV, not 1 Ω, so 1 V measured is
> *not* 1 A — the raw ADC voltage has to be scaled up to turn a shunt
> reading into amps: `a = rated_current / rated_shunt_voltage = 10 / 0.075
> ≈ 133.3` (leave `b = 0`). Concretely, at the shunt's full rated 10 A the
> raw Preview reads `0.075 V`, and `0.075 × 133.3 ≈ 10 A` — that's the
> multiplier doing its job. As with `PV_Current`, a negative reading means
> swapped leads (fix physically, or set `a=-133.3`), not a wiring fault.
> This isn't something to measure/derive yourself — it comes directly
> from the shunt's own rating, unlike the voltage divider below.

### PV_Voltage: calibrate against a multimeter

The divider's exact ratio depends on the resistors actually populated on
your board, so rather than trust a fixed number, measure it directly:

1. With the panel connected and in light, measure its voltage directly
   with a multimeter across the PV+/PV− leads. Call this `V_multimeter`.
2. Read the **raw, uncalibrated** value from the portal's Preview
   (`a=1, b=0` still set). Call this `V_raw`.
3. Set the calibration multiplier: `a = V_multimeter / V_raw` (leave
   `b = 0`).

**Worked example**: a multimeter reads `21.7 V` across the panel; the
portal's raw Preview shows `4.93 V`. Then
`a = 21.7 / 4.93 ≈ 4.40`, entered as the PV_Voltage calibration multiplier.
(This lines up with the divider's design target of scaling up to ~22 V down
to a ~5 V sensor range — expect `a` to land somewhere around 4-5 on this
board, but always calibrate against your own multimeter reading rather than
assuming that exact number.)

> **`WT_Voltage` uses this exact same procedure** — measure across the
> turbine's own output leads instead of the panel's, with the turbine
> spinning steadily, and calculate `a` the same way. It's the same divider
> design, just sized for the turbine's own rated voltage, so don't assume
> the same `a` value you got for `PV_Voltage` — calibrate it independently.

Re-run Preview after saving the calibration and confirm it now matches your
multimeter reading.

## 5. Set up MQTT → ThingsBoard

1. In ThingsBoard, create a device (**Devices → +  → Add new device**),
   give it a name (e.g. `PV-Panel-01` or `Wind-Turbine-01`), and save. If
   your enclosure has both a solar panel and a wind turbine wired in, they
   share one device — all four variables (`PV_Voltage`, `PV_Current`,
   `WT_Voltage`, `WT_Current`) come from the same logger and publish to the
   same topic, so one device/one access token covers both.
2. Open the device and copy its **access token** (device details →
   **Device credentials** → **Copy access token**, or in older ThingsBoard
   UIs, right-click the device → **Copy access token**).
3. Back in the Open Renewable Lab portal, under **MQTT**
   ([USER_MANUAL.md §7.1](USER_MANUAL.md#71-basic-settings)):

   | Field | Value |
   |---|---|
   | Enabled | ✓ |
   | Host | Your ThingsBoard instance's hostname (e.g. `demo.thingsboard.io`) |
   | Port | `8883` with **Use TLS** for UNIS Thingsboard |
   | Username | The device access token you copied |
   | Password | Leave blank |
   | Topic prefix | `v1/devices/me/telemetry` |
   | Flat telemetry topic | ✓ |

   <figure markdown>
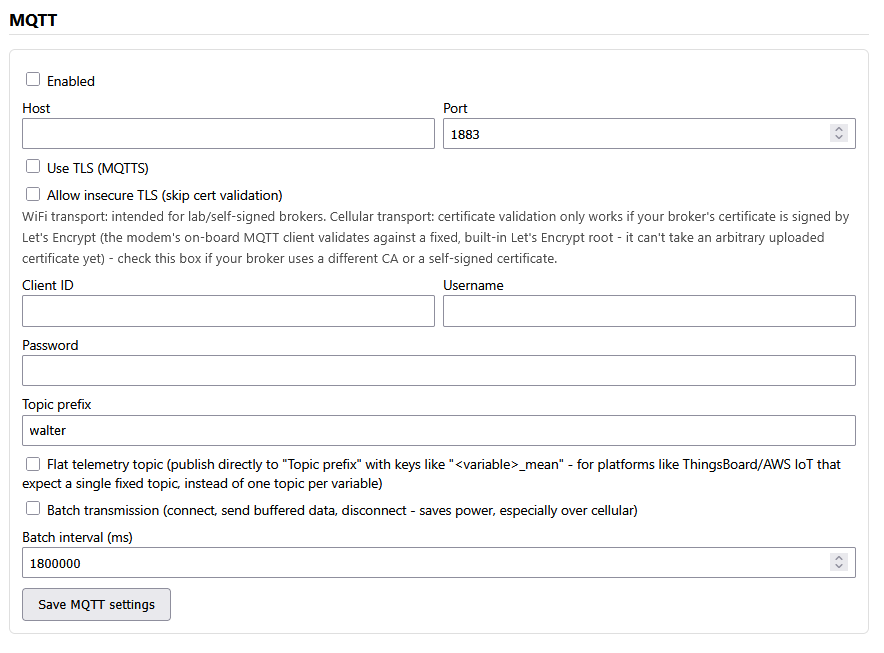
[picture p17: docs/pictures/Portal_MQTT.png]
Portal MQTT settings form
   
   <figcaption>
   The portal's MQTT settings form — the fields above map directly onto
   this.
   </figcaption>
   </figure>

   Save, then watch **MQTT connected** on the Status panel — see
   [USER_MANUAL.md §7.2](USER_MANUAL.md#72-testing-your-connection) if it
   doesn't come up.
4. While testing, you can temporarily shorten your variables' **Log/
   aggregate interval** (e.g. to `30000` ms) so you don't have to wait for
   the default 5-minute interval to see your first MQTT publish — see
   [USER_MANUAL.md §6.3](USER_MANUAL.md#63-understanding-sampling-vs-logging-vs-aggregation).
   Set it back to a sensible value once you've confirmed everything works.

## 6. Confirm data in ThingsBoard

Open the device in ThingsBoard and check its **Latest telemetry** tab. Once
a log interval has elapsed, you should see keys like `PV_Voltage_mean` and
`PV_Current_mean` (or `WT_Voltage_mean`/`WT_Current_mean` for the turbine —
one `<variable>_<aggregate>` key per aggregate you enabled on each
variable — see
[USER_MANUAL.md §7.3](USER_MANUAL.md#73-understanding-topics-and-payloads)
for the full payload shape). From here, you can build a ThingsBoard
dashboard with widgets charting these values in real time — see
ThingsBoard's own documentation for adding widgets to a dashboard.

Your data is also being logged to the SD card the whole time, independent
of MQTT — see [USER_MANUAL.md §10.1](USER_MANUAL.md#101-on-the-sd-card) if
you want a local backup or to analyze it in pandas/Excel later.

## Troubleshooting

See [USER_MANUAL.md §15](USER_MANUAL.md#15-troubleshooting) for general
issues (sensor not responding, MQTT never connecting, etc.). PV/wind
turbine-specific notes:

- **Preview fails / Scan I2C bus finds nothing at all**, on *every*
  address, not just `73`: check there's a **battery connected to BATT**.
  The external I2C bus (everything on AN1/AN2, and BATT's own LTC4015)
  is powered from a battery/PV-derived rail — running the board on USB
  alone with no battery, that whole bus is simply unpowered, which looks
  identical to "nothing responds." This is expected in that situation,
  not a fault.
- **PV_Voltage/WT_Voltage Preview reads ~0** with the panel in good light
  (or the turbine spinning) and a battery connected: check the plug is
  actually in **AN1** (not the **PV** gland, which won't measure anything
  — see [step 1](#1-how-the-analog-input-works)) and that the ADS111x
  input selected in the variable matches the connector you used
  (`AIN0`/`AIN1` for AN1, `AIN2`/`AIN3` for AN2), and that the I2C address
  is `73`.
- **`WT_Current` reads a value roughly 100× too small**: this is almost
  always a leftover `a=1` calibration copied from the PV setup — the wind
  turbine's shunt needs `a ≈ 133.3`, not `a=1` (see
  [step 4](#4-preview-and-calibrate)); `PV_Current`'s "no calibration
  needed" shortcut doesn't carry over.
- **Readings look reasonable but don't match your multimeter**: re-check
  the calibration multiplier from [step 4](#4-preview-and-calibrate) — a
  stale `a` from before you calibrated is the most common cause.

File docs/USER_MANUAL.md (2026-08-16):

# Walter Sensor Node — User Manual

This manual is for anyone setting up or operating a Walter Sensor Node —
no programming or firmware knowledge required. Everything described here is
done through your phone or laptop's web browser, via the device's built-in
setup portal.

If you're looking for how the firmware itself is built (to modify the code,
add a new sensor driver, etc.), see [DEVELOPER_GUIDE.md](DEVELOPER_GUIDE.md)
instead.

---

## Table of contents

1. [What is this?](#1-what-is-this)
2. [What you'll need](#2-what-youll-need)
3. [Quick start](#3-quick-start)
4. [Connecting to the portal](#4-connecting-to-the-portal)
5. [The Status panel](#5-the-status-panel)
6. [Adding sensors (Variables)](#6-adding-sensors-variables)
7. [Setting up MQTT](#7-setting-up-mqtt)
8. [Choosing your network](#8-choosing-your-network)
9. [Position reporting](#9-position-reporting)
10. [Where your data goes](#10-where-your-data-goes)
11. [Account and security](#11-account-and-security)
12. [Backup and restore](#12-backup-and-restore)
13. [Rebooting](#13-rebooting)
14. [How the setup hotspot behaves](#14-how-the-setup-hotspot-behaves)
15. [Troubleshooting](#15-troubleshooting)
16. [Glossary](#16-glossary)
17. [Quick reference](#17-quick-reference)

---

## 1. What is this?

The Walter Sensor Node is a small, self-contained environmental data logger
built around the Walter ESP32-S3 module and the Walter Feels carrier board.
It can:

- Read **SDI-12** sensors (soil moisture, weather stations, water level
  probes, etc. — anything speaking the SDI-12 protocol).
- Read **I2C** sensors (e.g. analog-to-digital converter boards for sensors
  that output a voltage).
- Log everything to a **microSD card** as CSV files you can open in Excel,
  Google Sheets, or pandas.
- Publish data to an **MQTT broker** over WiFi or a cellular (4G/LTE-M/NB-IoT)
  connection, so you can watch it live on a dashboard.
- Report its **GPS position** (cellular only), useful for mobile or
  multi-site deployments.
- Be fully configured **without writing any code** — every sensor, every
  timing setting, and every network/MQTT credential is set through a web
  page served by the device itself.

You never need to reflash the firmware to deploy a new sensor node or change
what it measures — you only reflash once, when the firmware itself changes.

---

## 2. What you'll need

- The Walter Sensor Node hardware, powered on (USB or the board's power
  input).
- A phone, tablet, or laptop with WiFi.
- Your sensors physically connected to the SDI-12 and/or I2C connectors
  on the carrier board (see your board's documentation for exact wiring —
  this manual covers the *software* side only).
- If you'll use MQTT: the address of an MQTT broker (ask your instructor or
  IT contact if you don't have one — a broker is free/easy to run for a lab
  setting, e.g. Mosquitto).
- If you'll use cellular data: a SIM card with a data plan, and its APN
  (Access Point Name — ask your carrier).
- A microSD card, formatted FAT32, inserted in the board, if you want local
  logging (recommended even if you're also using MQTT — it's your durable
  backup).

---

## 3. Quick start

For the impatient — the short version, expanded on in the sections below:

1. Power on the device.
2. On your phone/laptop, connect to the WiFi network named
   **`WalterSensor-XXXX`** (an open network, no WiFi password).
3. A login page should pop up automatically. If not, open a browser and go
   to `http://192.168.4.1/`.
4. Log in with the default password **`walter1234`**.
5. **Immediately change the password** (Portal password section).
6. Add your sensors under **Variables**.
7. Configure **MQTT** and/or **Network** if you want data sent off-device.
8. Done. The device starts sampling immediately; no reboot needed unless you
   changed the network transport.

---

## 4. Connecting to the portal

When the device boots, it starts a WiFi hotspot (access point) named
**`WalterSensor-XXXX`**, where `XXXX` is four characters unique to your
specific device (derived from its hardware address, so two devices never
clash). This hotspot is **open** — no WiFi password is needed to join it.

- The hotspot is active for the first **5 minutes** after every boot,
  whether or not anyone connects.
- After that, it stays on for as long as **at least one device is
  connected** to it, and switches off once the last device disconnects.
  See [section 14](#14-how-the-setup-hotspot-behaves) for the full
  explanation.

Once connected to the hotspot, most phones and laptops will automatically
pop up a "sign in to network" browser window (this is the same mechanism
used by hotel/airport WiFi). If it doesn't appear, open any browser and go
to:

```
http://192.168.4.1/
```

You'll see a login page asking for the **portal password**. The factory
default is:

```
walter1234
```

**Change this immediately** after your first login — see
[section 11](#11-account-and-security).

Once logged in, you stay logged in (via a browser cookie) for 30 minutes of
inactivity, after which you'll need to log in again. Up to 4 people can be
logged in to the same device at once (e.g. a few teammates on different
laptops).

---

## 5. The Status panel

The first thing you see after logging in is the **Status** panel, which
refreshes automatically every 5 seconds. Here's what each field means:

<figure markdown>
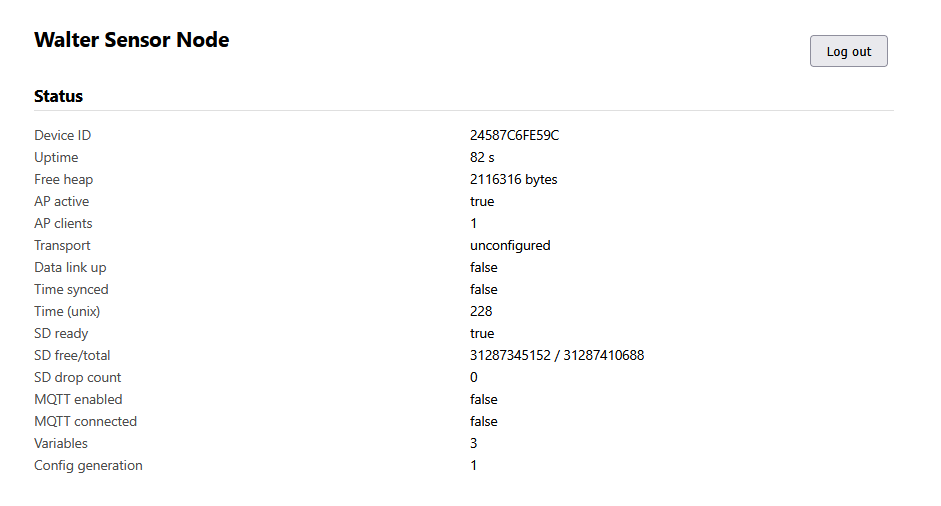
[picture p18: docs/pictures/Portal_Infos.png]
Portal Status panel

<figcaption>The Status panel, right after login.</figcaption>
</figure>

| Field | Meaning |
|---|---|
| Device ID | A unique, permanent 12-character ID for this specific device (derived from its hardware address). Used to tell devices apart in shared MQTT topics and to identify CSV files. |
| Uptime | How long since the device last booted. |
| Free heap | Available RAM, in bytes — mostly useful for diagnosing problems, not something you need to manage. |
| AP active | Whether the setup hotspot is currently on. |
| AP clients | How many devices are currently connected to the hotspot. |
| Transport | Which network transport is configured: `unconfigured`, `wifi`, or `cellular`. |
| Data link up | Whether the chosen transport (WiFi station / cellular) is actually connected right now. |
| Time synced | Whether the device has obtained the correct current time (via internet time sync, or cellular network time). Until this is true, logged timestamps aren't reliable — see [Troubleshooting](#15-troubleshooting). |
| SD ready | Whether the microSD card is mounted and working. |
| SD free/total | Free / total space on the SD card, in bytes. |
| SD drop count | Number of log entries that failed to write (card removed, full, etc). Should stay at 0 in normal operation. |
| MQTT enabled | Whether you've turned MQTT on in settings. |
| MQTT connected | Whether the device currently has an active MQTT connection. If batch transmission is on, this is only briefly `true` during each transmit window — see [section 7.4](#74-batch-transmission-saving-power). |
| Position enabled / Last fix | Only shown when transport is Cellular — whether position reporting is on, and the most recent GPS fix obtained. |
| Variables | How many sensors/variables you've configured. |
| Config generation | An internal counter that increases every time you change a setting — not something you need to act on. |

---

## 6. Adding sensors (Variables)

In this firmware, each individual measurement you want to record and report
is called a **variable** — e.g. "Soil Moisture 10cm" or "Battery Voltage."
A single physical sensor can produce more than one variable (e.g. a weather
station reporting both temperature and humidity would be two variables).

You can configure up to **32 variables** on one device.

### 6.1 Adding a variable

Click **+ Add variable** under the Variables section. You'll be asked for:

| Field | What to enter |
|---|---|
| Name | A short, unique label (e.g. `soil_temp_10cm`). This becomes the CSV column context and the MQTT topic segment for this variable, so keep it simple — letters, numbers, underscores. |
| Unit | Free text, e.g. `degC`, `%RH`, `V`. This is just a label shown in the portal and not interpreted by the firmware — use whatever makes sense to you. |
| Bus type | `SDI-12` or `I2C` — which physical bus the sensor is wired to. |
| *(SDI-12 sensors)* Address | The sensor's SDI-12 address: a single character `0`-`9`, `A`-`Z`, or `a`-`z`. Most sensors ship set to `0`; see [6.2](#62-finding-your-sensors-address) to find out what's actually on your bus. |
| *(SDI-12 sensors)* Parameter index | SDI-12 sensors often return several values in one reading (e.g. a soil probe might return moisture, temperature, and conductivity together). This is a zero-based index into that list: `0` for the first value, `1` for the second, etc. |
| *(I2C sensors)* I2C address | The sensor's 7-bit I2C address, in decimal (e.g. `72` for the common `0x48`). For the onboard sensor device types below, this defaults to that chip's fixed/typical address — see [6.5](#65-onboard-walter-feels-sensors-battery-temperature-humidity-pressure). |
| *(I2C sensors)* Device type | Which built-in driver to use to talk to this chip: `ADS111x` (external ADC, returns a voltage), `Generic` (a fallback that just reads a raw 16-bit register with no interpretation), or one of the **onboard Walter Feels sensors** (battery monitor, temperature, humidity, pressure — see [6.5](#65-onboard-walter-feels-sensors-battery-temperature-humidity-pressure)). |
| *(I2C sensors)* ADS111x input / Register address | For the ADC driver, a dropdown lets you pick which input to read: single-ended `AIN0`-`AIN3` (each measured against ground), or one of four **differential** pairs (`AIN0-AIN1`, `AIN0-AIN3`, `AIN1-AIN3`, `AIN2-AIN3` — the difference between the two inputs, useful for sensors like load cells/bridges/differential pressure that output a small voltage difference rather than a single-ended signal). For the generic driver, this field is instead a plain register address to read. |
| *(I2C sensors)* ADS111x gain / full-scale range | Only for the ADC driver: the input range the reading is scaled against, from `+/-6.144V` down to `+/-0.256V`. Pick the smallest range that still comfortably covers your signal's expected peak, for the best resolution — e.g. `+/-2.048V` for a 0–1.5V signal, `+/-6.144V` for a 0–5V signal. This does **not** change the chip's absolute maximum input voltage, which is always its own supply voltage + 0.3V regardless of gain — a 0–5V signal needs the ADS1115 itself powered from 5V, not 3.3V. Every ADS111x reading is actually an average of several conversions taken over 100ms, which rejects both 50Hz and 60Hz mains hum (see `ads111x.c`) — fine for slowly-varying signals like panel voltage or a pyranometer, but not intended for capturing fast transients. |
| Sample interval (ms) | How often the sensor is physically read, in milliseconds. Default: 60000 (once a minute). |
| Log/aggregate interval (ms) | How often a summary of the recent samples is written to SD/MQTT, in milliseconds. Must be **greater than or equal to** the sample interval. Default: 300000 (every 5 minutes). |
| Aggregates | Which statistics to compute and report over each log interval — see [6.3](#63-understanding-sampling-vs-logging-vs-aggregation). |
| Calibration multiplier (a) / offset (b) | Applied to every raw reading before logging/aggregation: `calibrated = a × raw + b`. Defaults (`a=1`, `b=0`) leave readings unchanged — see [6.6](#66-calibrating-a-variable-ax-b). |
| Enabled | Untick to keep the configuration saved but pause this variable without deleting it. |

### 6.2 Finding your sensor's address

If you don't know your SDI-12 sensor's address, or your I2C sensor's
address, use the **Scan SDI-12 bus** / **Scan I2C bus** buttons above the
variable list. This probes every possible address on the bus and reports
which ones respond. An SDI-12 scan can take a few seconds since it tries up
to 62 possible addresses. I2C results are shown as a decimal number with
the hex equivalent alongside (e.g. `72 (0x48)`) — enter the **decimal**
number into the "I2C address" field, since that field only accepts plain
decimal.

### 6.3 Understanding sampling vs. logging vs. aggregation

This is the most important concept to understand for meaningful data:

- **Sample interval**: how often the device actually takes a raw reading
  from the sensor. Think of this as your measurement resolution.
- **Log interval**: how often those raw samples get *summarized* into one
  row written to the SD card and/or sent over MQTT.
- **Aggregates**: which summary statistics are computed from all the raw
  samples collected during one log interval:
  - **raw** — just the single most recent sample (no averaging).
  - **mean** — the average of all samples in the interval.
  - **min** / **max** — the smallest/largest sample seen in the interval.
  - **stddev** — standard deviation, a measure of how much the readings
    varied during the interval (useful for spotting noisy sensors or
    unstable conditions).

**Example**: a soil moisture sensor with a sample interval of 10,000 ms
(every 10 seconds) and a log interval of 600,000 ms (every 10 minutes), with
"mean" and "stddev" checked, will take 60 raw readings every 10 minutes and
write one row containing their average and standard deviation. This
smooths out sensor noise while keeping your log file a manageable size.

If you only want the raw instantaneous value with no smoothing, set the
sample and log intervals equal, and check only "raw."

### 6.4 Testing a sensor (Preview)

Click **Preview** next to any configured variable to take one reading right
now and see the result immediately, without waiting for its next scheduled
sample. Use this to confirm a sensor is wired correctly and returning
sensible values before you leave it to log unattended.

### 6.5 Onboard Walter Feels sensors (battery, temperature, humidity, pressure)

The Walter Feels carrier board itself has built-in sensors, wired to the
same I2C bus as the external connector (so they *do* show up if you use
the "Scan I2C bus" button — you don't need it for these, since their
addresses are already known and listed below). To use one, add a
variable with bus type `I2C` and pick one of these device types:

| Device type | Reads | Typical I2C address |
|---|---|---|
| Onboard HDC1080 - Temperature | Board temperature (°C) | `64` (`0x40`) |
| Onboard HDC1080 - Humidity | Board relative humidity (%RH) | `64` (`0x40`) |
| Onboard LPS22HB - Pressure | Barometric pressure (hPa) | `92` (`0x5C`) or `93` (`0x5D`) |
| Onboard LPS22HB - Temperature | A second temperature reading, from the pressure sensor | `92` (`0x5C`) or `93` (`0x5D`) |
| Onboard LTC4015 - Battery monitor | Battery voltage, input voltage, battery current, or charger temperature (pick one via the "LTC4015 reading" dropdown) | `104` (`0x68`) |

For the battery monitor's **voltage** reading specifically, set your
battery's chemistry and cell count under the **Battery monitor** section
of the settings page — this isn't a fixed board setting, since different
stations may use different batteries (Li-Ion, LiFePO4, or lead-acid).
Getting this wrong won't damage anything, but will scale the reported
voltage incorrectly.

<figure markdown>
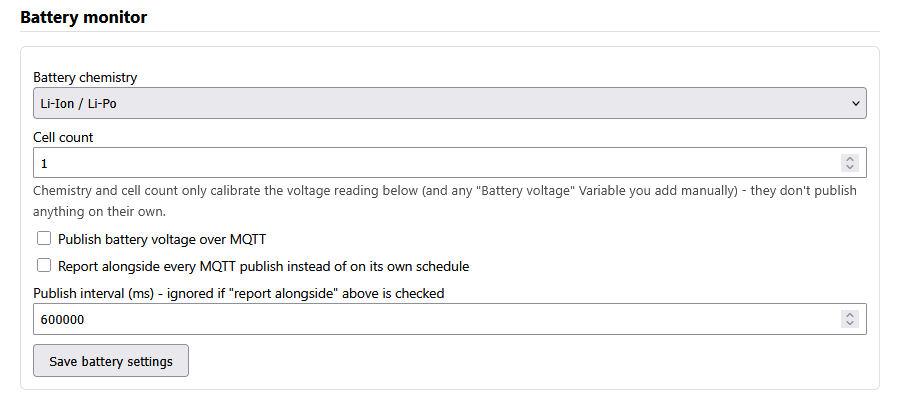
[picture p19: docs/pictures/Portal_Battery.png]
Portal Battery monitor settings

<figcaption>The Battery monitor settings section.</figcaption>
</figure>

### 6.6 Calibrating a variable (a·x + b)

Every variable has a **calibration multiplier (a)** and **calibration
offset (b)**, applied to every raw reading before it's logged or
aggregated: `calibrated = a × raw + b`. The defaults (`a=1`, `b=0`) leave
readings unchanged.

The most common use is correcting a voltage divider: if you're measuring
a voltage through a divider that scales it down by some ratio before it
reaches the ADC, set `a` to the divider's inverse ratio to recover the
original voltage. For example, a divider built from a 10 kΩ and 1 kΩ
resistor (ratio 1/11) needs `a = 11` so a divided reading of 0.4 V is
reported as the true 4.4 V.

It's also useful for a simple two-point sensor calibration: if a sensor
reads 0.2 when the true value is 0 and 10.4 when the true value is 10,
solve for `a` and `b` from those two points (`a ≈ 0.98`, `b ≈ -0.196`) and
enter them here.

### 6.7 Editing and deleting variables

Use **Edit** to change any field of an existing variable, or **Delete** to
remove it entirely (this does not delete already-logged data).

---

## 7. Setting up MQTT

[MQTT](#16-glossary) lets your device publish data in near-real-time to a
central server (a "broker"), which any dashboard, database, or script can
subscribe to. This is optional — the device logs to SD card regardless of
whether MQTT is configured.

**MQTT stays completely off until you explicitly enable it** — the device
won't attempt any connection with default settings.

### 7.1 Basic settings

| Field | What it means |
|---|---|
| Enabled | Master on/off switch for MQTT. |
| Host | Your broker's hostname or IP address. |
| Port | Your broker's port. Common defaults: `1883` (plain) or `8883` (TLS). |
| Use TLS (MQTTS) | Encrypt the connection. Recommended whenever your broker supports it, especially over cellular or a shared WiFi network. |
| Allow insecure TLS | Skips verifying the broker's certificate. Only use this for testing against a broker with a self-signed certificate — it removes protection against impersonation. |
| Client ID | An identifier your broker uses to distinguish this connection. Leave blank unless your broker requires something specific. |
| Username / Password | Your broker credentials, if it requires authentication. The password field is write-only — once set, the portal shows "(already set)" rather than displaying it back to you. |
| Topic prefix | The first part of every MQTT topic this device publishes to (see [7.3](#73-understanding-topics-and-payloads)). Default: `walter`. |
| Flat telemetry topic | Off by default (see [7.3](#73-understanding-topics-and-payloads)). Turn this on for platforms like **ThingsBoard** or AWS IoT that expect a single fixed telemetry topic rather than one topic per variable — set **Topic prefix** to that platform's exact topic (e.g. ThingsBoard's `v1/devices/me/telemetry`) and check this box. |

### 7.2 Testing your connection

After saving MQTT settings, watch the **MQTT connected** field on the
Status panel. If it stays `false` for longer than expected, double-check
host/port/credentials, and confirm your device actually has network
connectivity (**Data link up** on the Status panel).

### 7.3 Understanding topics and payloads

Every variable is published to its own topic:

```
<topic_prefix>/<device_id>/<variable_name>
```

For example, with the default prefix `walter`, a device with ID
`AABBCCDDEEFF` and a variable named `soil_temp`, the topic is:

```
walter/AABBCCDDEEFF/soil_temp
```

Including the device ID in every topic means **multiple sensor nodes can
publish to the same broker under the same topic prefix** without their data
colliding — just subscribe to `walter/#` to see everything, or
`walter/AABBCCDDEEFF/#` for one specific device.

The message payload is JSON containing whichever aggregates you enabled for
that variable, plus a timestamp and sample count. For example, a variable
with "mean" and "max" enabled might publish:

```json
{"ts": 1752345600, "time_synced": true, "n": 60, "mean": 21.4, "max": 23.1}
```

- `ts` — Unix timestamp (seconds since 1970-01-01 UTC) of when this
  aggregate was finalized.
- `time_synced` — `false` if the device hadn't yet obtained the correct
  time when this was logged (see [Troubleshooting](#15-troubleshooting));
  treat `ts` with suspicion if so.
- `n` — how many raw samples went into this aggregate.
- Then one field per aggregate you enabled (`raw`, `mean`, `min`, `max`,
  `stddev` — only the ones you checked appear).

If you've enabled position reporting (cellular only — see
[section 9](#9-position-reporting)), position is published separately to:

```
<topic_prefix>/<device_id>/position
```

Position works exactly like a variable with four fields (latitude,
longitude, elevation, horizontal precision) instead of one — each fix is
folded into the same kind of running aggregate, and only the aggregates
you've checked appear, one key per `<field>_<aggregate>`:

```json
{"ts": 1752345600, "time_synced": true, "n": 8, "lat_mean": 78.9231, "lat_stddev": 0.00004, "lon_mean": 11.9349, "lon_stddev": 0.00006, "elevation_m_mean": 12.4, "elevation_m_stddev": 1.1, "h_precision_m_mean": 6.2, "h_precision_m_stddev": 0.8}
```

`h_precision_m` is the GNSS fix's own estimated horizontal confidence in
meters (smaller = more confident) — useful for spotting a poor-quality
fix rather than trusting every reported position equally.

#### Flat telemetry topic (ThingsBoard, AWS IoT, etc.)

Some platforms don't work with a per-variable topic scheme at all — they
identify the device from the MQTT connection itself (usually the
username/access token) and only look at one fixed topic, ignoring
anything published elsewhere. **ThingsBoard** is the common example: its
device API only reads `v1/devices/me/telemetry`, so a per-variable topic
like `v1/devices/me/telemetry/AABBCCDDEEFF/soil_temp` is silently
dropped — the device can still show as "online" (that only reflects the
MQTT connection succeeding), while no telemetry ever appears.

Checking **Flat telemetry topic** changes both the topic and the payload
shape:

- Every publish goes to the literal **Topic prefix** — no device ID or
  variable name appended.
- The payload uses one flat JSON key per variable *and* aggregate, named
  `<variable_name>_<aggregate>`, instead of the `{"mean": ..., "stddev": ...}`
  shape above. A variable named `soil_temp` with "mean" and "stddev"
  enabled publishes:
  ```json
  {"soil_temp_mean": 21.4, "soil_temp_stddev": 0.3}
  ```

For ThingsBoard specifically: set **Topic prefix** to `v1/devices/me/telemetry`,
check **Flat telemetry topic**, and use your device's access token as the
MQTT **Username** (leave Password blank).

### 7.4 Batch transmission (saving power)

If you're running on battery/solar and using cellular data, keeping the
modem connected continuously uses significant power. **Batch transmission**
lets you trade a bit of latency for much lower power use:

- **Off (default)**: the device stays connected to your broker and
  publishes each result the moment it's ready.
- **On**: the device stays *disconnected* most of the time, quietly
  collecting results in memory. Once every **batch interval**, it connects,
  sends everything it's collected, and disconnects again.

To enable it, check **Batch transmission** under MQTT settings and set a
**Batch interval (ms)** — e.g. `1800000` for every 30 minutes (the
default). SD card logging is completely unaffected by this setting; only
the MQTT connection behavior changes.

**A word of caution on sizing**: the device holds pending messages in a
fixed-size buffer (256 entries) while waiting for the next transmit window.
If you have many variables logging frequently and set a very long batch
interval, you could exceed this and lose some MQTT messages (though never
your SD card log, which is unaffected). As a rule of thumb, keep
`batch_interval_ms ÷ shortest_log_interval_ms × number_of_variables` well
under 256.

---

## 8. Choosing your network

Under **Network**, choose how the device gets online for MQTT/position
reporting (this is separate from the always-available setup hotspot):

<figure markdown>
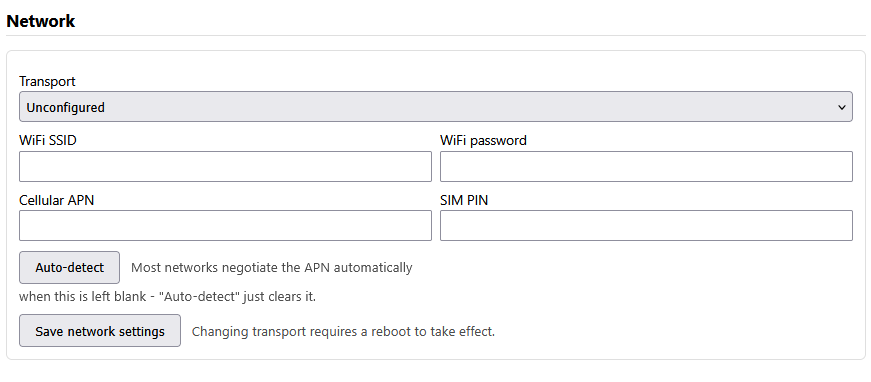
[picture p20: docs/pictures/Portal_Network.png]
Portal Network settings

<figcaption>The Network settings section, transport set to Unconfigured.</figcaption>
</figure>

| Transport | When to use it |
|---|---|
| Unconfigured (default) | No data connection — the device still samples and logs to SD, just doesn't publish anywhere. |
| WiFi | The device joins an existing WiFi network as a client, in addition to running its own setup hotspot. |
| Cellular | The device uses its built-in cellular modem (4G/LTE-M/NB-IoT) for data — needed for position reporting too. |

For **WiFi**, enter the SSID and password of the network to join.

For **Cellular**, enter your SIM's **APN** and, if the SIM requires one, its
**PIN** — leave the PIN blank unless you know your SIM actually needs one.
Many IoT/M2M SIMs ship with PIN lock disabled entirely, and repeatedly
trying a wrong PIN risks permanently locking the SIM (most SIMs allow
only 3 attempts before requiring a PUK code). If you don't know your APN,
most networks negotiate it automatically when left blank — click
**Auto-detect** to clear the field rather than guessing.

> **Changing the transport requires a reboot** to take effect — the portal
> will tell you when this is the case after saving. Other settings (MQTT
> credentials, variables, position interval, etc.) apply immediately with
> no reboot needed.

---

## 9. Position reporting

If your device uses a **Cellular** connection, it can also report its GPS
position — useful for tracking a mobile deployment or confirming a fixed
station's install location. This is not available over WiFi, since the GPS
receiver is built into the same chip as the cellular modem.

> ⚠ **Requires a physical GNSS/GPS antenna connected to the modem.**
> Without one, the device will keep trying and failing to get a fix
> (harmless, just logged) but will never actually report a position — the
> portal warns about this directly above the Position reporting settings.

<figure markdown>
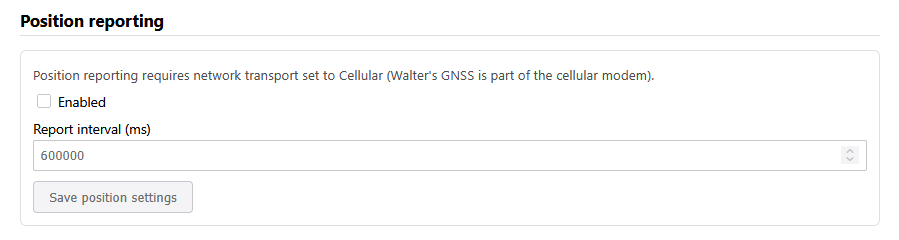
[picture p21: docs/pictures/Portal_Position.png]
Portal Position reporting settings

<figcaption>
The Position reporting section (grayed out here since transport isn't set
to Cellular).
</figcaption>
</figure>

Position works the same way as a sensor variable — latitude, longitude,
elevation, and horizontal precision are each treated as their own field,
sampled and aggregated on the same schedule — just kept as its own section
rather than one more entry in the Variables list, since it's device-wide
rather than per-sensor. Under **Position reporting**:

- **Enabled** — turn position reporting on/off.
- **Sample interval (ms)** — how often to attempt a GPS fix. A cold fix can
  take up to about a minute and briefly interrupts the cellular connection
  (GPS and LTE share the modem's one antenna), so keep this reasonably
  long — the default is `600000` (10 minutes).
- **Log/aggregate interval (ms)** — how often the fixes collected since the
  last log are aggregated into one record and logged/published. Must be
  `>=` the sample interval. Default: `600000` (10 minutes, same as sample
  interval — one fix in, one record out, by default).
- **Aggregates** — same `raw`/`mean`/`min`/`max`/`stddev` choices as a
  variable (see [section 6.3](#63-understanding-sampling-vs-logging-vs-aggregation)),
  applied independently to latitude, longitude, elevation, and horizontal
  precision. If you set the sample interval shorter than the log interval,
  `mean` gives you a position averaged over several fixes — steadier, but
  only meaningful for a station that isn't moving between fixes.

Position records are logged to a separate CSV file on the SD card (see
[section 10](#10-where-your-data-goes)) and published over MQTT if enabled,
following the same batching behavior as your sensor data.

---

## 10. Where your data goes

### 10.1 On the SD card

The **SD logging** settings section lets you choose between three CSV
layouts. Changing this only affects newly-created files — it doesn't
rewrite anything already logged.

<figure markdown>
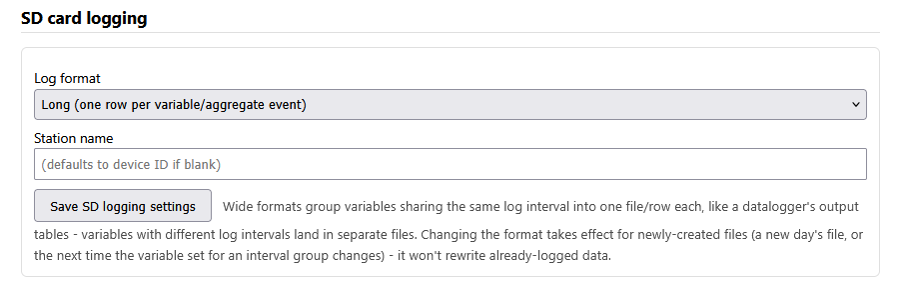
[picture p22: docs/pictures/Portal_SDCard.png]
Portal SD card logging settings

<figcaption>The SD card logging settings section.</figcaption>
</figure>

**Long (default)** — one row per variable per aggregate event, all
variables and days interleaved into `sensors_YYYYMMDD.csv` (UTC date),
e.g. `sensors_20260713.csv`:

```
# device_id=AABBCCDDEEFF
timestamp_unix,time_synced,variable_id,name,sample_count,aggregate_mask,raw,mean,min,max,stddev
```

Every column after the header is always present in every row (raw/mean/
min/max/stddev are always computed internally and written, regardless of
which aggregates you selected) — `aggregate_mask` tells you which ones you
actually asked for; the rest can be ignored.

**Wide, simple header / Wide, TOA5 format** — one row per "scan" instead,
with one column per variable+aggregate, similar to how a Campbell
Scientific datalogger writes its output tables. Variables that share the
same **log interval** land together in one file/row; variables with a
different log interval go to a separate file — so if you have a fast
10-second variable and a slow 5-minute variable, you'll get two wide
files, each internally synchronized. Files are named
`sensors_iv<interval>_<hash>_YYYYMMDD.csv` (the hash changes automatically
if you edit which variables/aggregates feed that interval group, so an
older file's columns never get silently misaligned by a later edit).

- **Wide, simple header** looks like:
  ```
  # station_name=greenhouse-1,device_id=AABBCCDDEEFF,interval_ms=60000
  timestamp_unix,time_synced,record,PV_Voltage_mean_V,PV_Voltage_stddev_V,PV_Current_mean_A
  1752345600,1,0,21.40,0.30,1.05
  ```
- **Wide, TOA5 format** matches Campbell Scientific's TOA5 layout (a
  4-line header: file info, quoted field names, units, and
  aggregate-type per column) and is importable directly by TOA5-aware
  tools:
  ```
  "TOA5","greenhouse-1","WalterSensorNode","AABBCCDDEEFF","IDFv6.0.2","walter_sensor_node","0","Interval_60s"
  "TIMESTAMP","RECORD","PV_Voltage_Avg","PV_Voltage_Std","PV_Current_Avg"
  "TS","RN","V","V","A"
  "","","Avg","Std","Avg"
  "2026-07-13 12:00:00",0,21.40,0.30,1.05
  ```

A blank cell in a wide row means that particular variable didn't report
in time for that scan (e.g. a sensor briefly disconnected) — the row is
still written once the log interval elapses, rather than waiting forever.

If the device hasn't yet obtained the correct time when it writes a file,
that data lands in a `..._19700101.csv` file instead — a clearly-labeled
"unsynced" bucket rather than a wrong date (applies to all three formats).

Position fixes (cellular only, if enabled) always go to a separate file
regardless of the SD logging format setting, `position_YYYYMMDD.csv`. Like
the Long sensor format, every raw/mean/min/max/stddev column is always
present — `aggregate_mask` tells you which ones you actually asked for:

```
timestamp_unix,time_synced,sample_count,aggregate_mask,lat_raw,lat_mean,lat_min,lat_max,lat_stddev,lon_raw,lon_mean,lon_min,lon_max,lon_stddev,elevation_m_raw,elevation_m_mean,elevation_m_min,elevation_m_max,elevation_m_stddev,h_precision_m_raw,h_precision_m_mean,h_precision_m_min,h_precision_m_max,h_precision_m_stddev
```

All of these can be opened directly in Excel, Google Sheets, or loaded
with `pandas.read_csv(path, comment='#')` for the Long/Wide-simple formats
(the `comment='#'` skips the info line automatically) — TOA5 files are
best read with a TOA5-aware reader (e.g. Campbell's Loggernet, or common
R/Python TOA5 packages) since their header uses more than one line.

### 10.2 Over MQTT

See [section 7.3](#73-understanding-topics-and-payloads).

---

## 11. Account and security

<figure markdown>
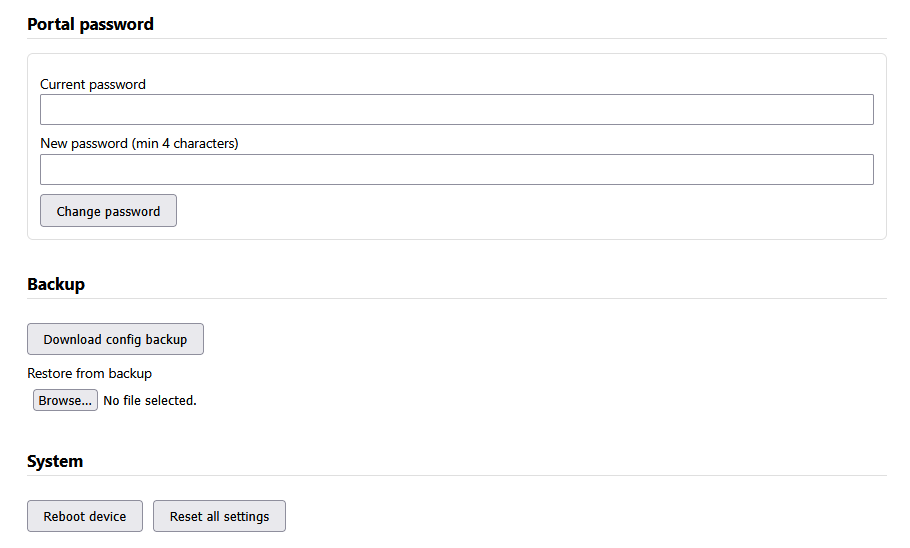
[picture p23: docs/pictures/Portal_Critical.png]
Portal password, Backup, and System sections

<figcaption>
The bottom of the settings page: Portal password (this section), Backup
([section 12](#12-backup-and-restore)), and System
([section 13](#13-rebooting)) all together.
</figcaption>
</figure>

### 11.1 Changing the password

Under **Portal password**, enter your current password and a new one (at
least 4 characters) to change it. **Do this before any real deployment** —
the factory default (`walter1234`) is publicly documented and should never
be left in place, since the setup hotspot is open to anyone nearby during
its active windows.

### 11.2 Session behavior

Logging in creates a session that stays valid for 30 minutes of inactivity
(each authenticated action resets the timer). Up to 4 sessions can be active
at once. There's no need to explicitly log out, though a **Log out** button
is provided if you want to end your session immediately (e.g. on a shared
computer).

---

## 12. Backup and restore

Under **Backup**:

- **Download config backup** saves your entire configuration (variables,
  MQTT/network settings, portal password *hash*, etc.) as a JSON file.
  Secrets (MQTT password, WiFi password, SIM PIN) are deliberately left out
  of this file for safety — restoring a backup keeps whatever secrets are
  already saved on the device rather than blanking them.
- **Restore from backup** uploads a previously downloaded file and applies
  it, useful for cloning a configuration across several devices or
  recovering after a factory reset.

Restoring a backup that changes the network transport will require a
reboot, same as changing it manually.

---

## 13. Rebooting

Click **Reboot device** under System to restart the firmware — needed after
changing network transport, and occasionally useful as a general
troubleshooting step. The device will be briefly unreachable while it
restarts (typically a few seconds), then the setup hotspot will reappear.

---

## 14. How the setup hotspot behaves

The `WalterSensor-XXXX` hotspot is designed to be available whenever you
need it, without staying on and consuming power/airtime forever:

- It's **always on for the first 5 minutes** after every boot, regardless
  of whether anyone connects.
- After that grace period, it **stays on as long as at least one device is
  connected**, and turns off automatically once the last device
  disconnects.
- This is completely independent of your chosen data transport — the
  hotspot works the same way whether the device is using WiFi, Cellular, or
  no transport at all for its actual data.

In practice: if you need to reconfigure a device that's been running
unattended for a while, connect within the first 5 minutes of a fresh boot
(power-cycle it if needed), or note that the hotspot only reappears on
reboot if nothing is holding it open.

---

## 15. Troubleshooting

**Can't find the `WalterSensor-XXXX` network.**
Confirm the device is powered on. If it's been running for a while with no
one connected, the hotspot may have timed out — power-cycle the device to
get a fresh 5-minute window (see [section 14](#14-how-the-setup-hotspot-behaves)).

**Captive portal page doesn't pop up automatically.**
Manually browse to `http://192.168.4.1/`.

**Forgot the portal password.**
There's no remote password reset in this firmware — you'll need physical/
serial access to the device to recover it (ask whoever manages your lab's
firmware). This is why changing the default password promptly, and
recording your new one somewhere safe, matters.

**A sensor's Preview shows no value / fails.**
- Confirm the sensor is physically wired to the correct bus and powered.
- For SDI-12, confirm the address is correct via **Scan SDI-12 bus**.
- For I2C, confirm the address is correct via **Scan I2C bus**, and that
  you've picked the right Device type ID for your chip.
- If nothing on the bus responds to a scan at all, the issue is likely
  wiring/power rather than configuration.

**No data appearing on the SD card.**
- Check **SD ready** on the Status panel. If `false`, the card may not be
  inserted, may not be formatted FAT32, or may not be making good contact.
- Check **SD drop count** — a nonzero and growing value suggests a flaky
  card or a filesystem problem.
- Confirm at least one variable is **Enabled**.

**MQTT never connects.**
- Confirm **MQTT enabled** is checked and settings are saved.
- Confirm **Data link up** is `true` on the Status panel — MQTT can't work
  without underlying network connectivity.
- Double check host/port/credentials, and TLS setting matches what your
  broker expects.
- If batch transmission is on, `MQTT connected` will only briefly flash
  `true` once per batch window — this is expected, not a failure.

**Time never syncs (`time_synced` stays false).**
- Over WiFi: the device needs working internet access (not just a local
  network) to reach an NTP time server.
- Over Cellular: time comes from the network once registered; confirm
  **Data link up** is true.
- Until time syncs, logged timestamps use a fallback and are marked
  `time_synced: false` / land in the `*_19700101.csv` files — the
  measurements themselves are still valid, just not reliably timestamped
  yet.

**Position reporting shows no fix.**
- Confirm a **GNSS/GPS antenna is physically connected** to the modem —
  by far the most common cause. Without one, the device just keeps
  retrying silently forever; nothing in the portal can detect a missing
  antenna for you.
- Confirm transport is set to **Cellular** (position isn't available over
  WiFi) and **Position enabled** is checked.
- A GPS fix needs a clear view of the sky and can take up to about a
  minute, especially the first one after power-on ("cold start").

---

## 16. Glossary

| Term | Meaning |
|---|---|
| SDI-12 | A serial communication standard widely used by environmental sensors (soil, weather, water) — a multi-drop bus where several sensors share one cable, each with its own address. |
| I2C | A common two-wire chip-to-chip communication bus, often used to connect small sensor/ADC boards. |
| MQTT | A lightweight publish/subscribe messaging protocol widely used in IoT — devices publish data to "topics" on a central "broker," and anyone subscribed to that topic receives it. |
| MQTTS | MQTT over an encrypted (TLS) connection. |
| Broker | The central server that MQTT clients (like this device) connect to and publish data through. |
| Topic | The named "channel" a piece of MQTT data is published under, e.g. `walter/AABBCCDDEEFF/soil_temp`. |
| APN | Access Point Name — an identifier your cellular carrier uses to configure your data connection; ask your carrier for the correct value. |
| GNSS / GPS | Satellite positioning. This firmware uses "GNSS" and "GPS" interchangeably; the receiver is built into the cellular modem chip. |
| Aggregate | A summary statistic (mean, min, max, standard deviation, or the last raw value) computed from several sensor readings over one logging interval. |
| Captive portal | The automatic "sign in to this network" popup your phone/laptop shows when joining certain WiFi hotspots — this is how you first reach the setup page. |
| NVS | Non-Volatile Storage — the device's persistent flash-based settings storage. Your configuration survives power loss and reboots because it's saved here. |
| Device ID | A permanent, unique identifier for this specific device, derived from its hardware address — see the Status panel. |

---

## 17. Quick reference

**Default portal password**: `walter1234` (change immediately)

**Default hotspot SSID**: `WalterSensor-XXXX` (open network, no password)

**Portal URL**: `http://192.168.4.1/`

**Default MQTT port**: `1883` (or `8883` for TLS)

**Default MQTT topic prefix**: `walter`

**MQTT topic format**: `<topic_prefix>/<device_id>/<variable_name>`
(position: `<topic_prefix>/<device_id>/position`) — or the literal
`<topic_prefix>` with `<variable_name>_<aggregate>` payload keys if
**Flat telemetry topic** is enabled (ThingsBoard, AWS IoT, etc.)

**SD card path**: `/data/sensors_YYYYMMDD.csv` and `/data/position_YYYYMMDD.csv`

**Default sample interval**: 60,000 ms (1 minute)

**Default log interval**: 300,000 ms (5 minutes)

**Default MQTT batch interval**: 1,800,000 ms (30 minutes)

**Default position sample/log interval**: 600,000 ms (10 minutes) each

**Max variables per device**: 32

**Session timeout**: 30 minutes of inactivity (up to 4 concurrent sessions)

**Setup hotspot**: on for 5 minutes after boot, then stays on while ≥1
device is connected

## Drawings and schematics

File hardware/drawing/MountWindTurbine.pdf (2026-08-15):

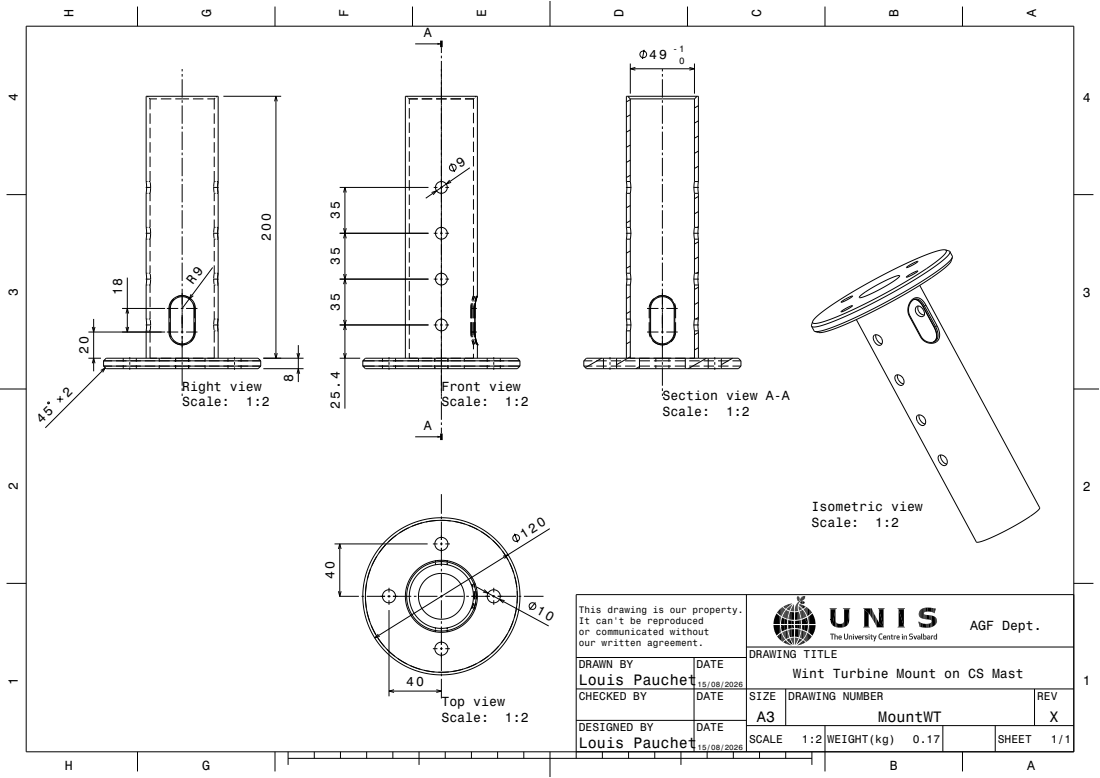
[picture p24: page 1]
DRAWING TITLE; AGF Dept.; Front view Scale: 1:2; Right view; Scale: 1:2200; Top view Scale: 1:2; Section view A-A Scale: 1:2; Isometric view Scale: 1:2

This drawing is our property.
It can't be reproduced
or communicated without
our written agreement.

DRAWN BY | DATE 15/08/2026 | Wint Turbine Mount on CS Mast Louis Pauchet

CHECKED BY | DATE | SIZE A3 | DRAWING NUMBER MountWT | REV X

DESIGNED BY Louis Pauchet15/08/2026 | DATE

SCALE 1:2 | WEIGHT(kg) 0.17 | SHEET 1/1

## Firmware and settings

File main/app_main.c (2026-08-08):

#include <inttypes.h>

#include "battery_monitor.h"
#include "board_pins.h"
#include "cellular_transport.h"
#include "config_store.h"
#include "device_id.h"
#include "esp_chip_info.h"
#include "esp_flash.h"
#include "esp_log.h"
#include "esp_pm.h"
#include "esp_system.h"
#include "freertos/FreeRTOS.h"
#include "freertos/queue.h"
#include "freertos/task.h"
#include "gnss_position.h"
#include "i2c_bus.h"
#include "i2c_sensor_registry.h"
#include "mqtt_client_bridge.h"
#include "net_manager.h"
#include "onboard_i2c_bus.h"
#include "sampling_engine.h"
#include "sd_logger.h"
#include "sdi12_bus.h"
#include "stub_sensor.h"
#include "time_sync.h"
#include "web_portal.h"

static const char *TAG = "app_main";

/* Lightweight console visibility: logs every finalized aggregate
 * alongside the SD/MQTT sinks - handy during bring-up and for a
 * student watching the serial monitor. */
static void debug_result_sink_task(void *pvParams)
{
    QueueHandle_t queue = (QueueHandle_t)pvParams;
    aggregate_result_t result;
    for (;;) {
        if (xQueueReceive(queue, &result, portMAX_DELAY) == pdTRUE) {
            ESP_LOGI(TAG,
                     "[%s] n=%" PRIu32 " raw=%.2f mean=%.2f min=%.2f max=%.2f stddev=%.2f synced=%d",
                     result.name, result.sample_count, result.raw, result.mean, result.min, result.max,
                     result.stddev, (int)result.time_is_synced);
        }
    }
}

void app_main(void)
{
    /* Power management: allow the CPU to clock down to XTAL frequency
     * (40MHz) and the idle task to drop into automatic light sleep
     * whenever nothing has work to do, rather than always running at
     * the configured max (160MHz, CONFIG_ESP_DEFAULT_CPU_FREQ_MHZ) -
     * this station is meant to run on battery/solar, and every
     * subsystem here is already event/timer-driven (sampling_engine's
     * per-variable schedules, sd_logger's queue, mqtt_client_bridge,
     * etc.), so none of them need to be rewritten for this to help:
     * the idle task just stops spinning between their wakeups. Requires
     * CONFIG_PM_ENABLE + CONFIG_FREERTOS_USE_TICKLESS_IDLE (see
     * sdkconfig.defaults); guarded here so this still builds (as a
     * no-op) if those are ever turned off via menuconfig. Note this can
     * make the USB-Serial-JTAG console feel less responsive right after
     * an idle period (the link itself can briefly sleep too) - a
     * cosmetic monitor-only side effect, not a functional one. */
#if CONFIG_PM_ENABLE
    esp_pm_config_t pm_config = {
        .max_freq_mhz = 160,
        .min_freq_mhz = 40,
#if CONFIG_FREERTOS_USE_TICKLESS_IDLE
        .light_sleep_enable = true,
#endif
    };
    ESP_ERROR_CHECK(esp_pm_configure(&pm_config));
#endif

    /* Must happen before any peripheral bus init below - the external
     * I2C connector, onboard I2C sensor bus, and SD card are all fed
     * from this switched rail on Walter Feels (see board_pins.h). */
    board_pins_enable_3v3_sw();

    esp_chip_info_t chip_info;
    esp_chip_info(&chip_info);

    uint32_t flash_size = 0;
    esp_flash_get_size(NULL, &flash_size);

    ESP_LOGI(TAG, "Walter sensor node booting, device_id=%s", device_id_get());
    ESP_LOGI(TAG, "chip: %s, cores: %d, revision: v%d.%d",
             CONFIG_IDF_TARGET, chip_info.cores,
             chip_info.revision / 100, chip_info.revision % 100);
    ESP_LOGI(TAG, "flash: %" PRIu32 "MB, free heap: %" PRIu32 " bytes",
             flash_size / (1024 * 1024), esp_get_free_heap_size());

    ESP_ERROR_CHECK(config_store_init());
    device_config_t cfg;
    config_store_get_snapshot(&cfg);
    ESP_LOGI(TAG, "config loaded: %u variable(s), generation=%" PRIu32,
             (unsigned)cfg.variable_count, cfg.generation);

    if (sdi12_bus_init() == ESP_OK) {
        sampling_engine_register_bus_driver(BUS_TYPE_SDI12, sdi12_variable_read);
    } else {
        ESP_LOGW(TAG, "SDI-12 bus unavailable (board_pins.h SDI-12 pins not configured), using stub sensor");
        sampling_engine_register_bus_driver(BUS_TYPE_SDI12, stub_sensor_read);
    }
    if (i2c_bus_init() == ESP_OK) {
        sampling_engine_register_bus_driver(BUS_TYPE_I2C, i2c_variable_read);
    } else {
        ESP_LOGW(TAG, "I2C bus unavailable (board_pins.h I2C pins not configured), using stub sensor");
        sampling_engine_register_bus_driver(BUS_TYPE_I2C, stub_sensor_read);
    }
    /* Separate physical bus from the one above (Walter Feels' onboard
     * HDC1080/LPS22HB sensors) - i2c_variable_read() already routes to
     * whichever bus a given I2C device_type actually lives on, so no
     * separate BUS_TYPE/driver registration is needed here, just init. */
    if (onboard_i2c_bus_init() != ESP_OK) {
        ESP_LOGW(TAG, "onboard sensor I2C bus unavailable (board_pins.h pins not configured) - "
                      "HDC1080/LPS22HB variables will fail to read");
    }
    ESP_ERROR_CHECK(sampling_engine_init());
    ESP_ERROR_CHECK(battery_monitor_init());

    QueueHandle_t debug_sink = xQueueCreate(16, sizeof(aggregate_result_t));
    ESP_ERROR_CHECK(sampling_engine_add_result_sink(debug_sink));
    xTaskCreate(debug_result_sink_task, "debug_sink", 4096, debug_sink, tskIDLE_PRIORITY + 1, NULL);

    if (sd_logger_init() == ESP_OK) {
        ESP_ERROR_CHECK(sampling_engine_add_result_sink(sd_logger_get_sink_queue()));
    } else {
        ESP_LOGW(TAG, "SD logging unavailable (no card, or board_pins.h SD pins not yet configured)");
    }

    ESP_ERROR_CHECK(net_manager_init());
    ESP_ERROR_CHECK(web_portal_init());
    ESP_ERROR_CHECK(time_sync_init());

    if (cfg.net.transport == TRANSPORT_CELLULAR) {
        if (cellular_transport_init() == ESP_OK) {
            ESP_ERROR_CHECK(gnss_position_init());
        } else {
            ESP_LOGE(TAG, "cellular_transport_init failed - see its header for the unverified-SDK-calls caveat");
        }
    }

    ESP_ERROR_CHECK(mqttc_init());
}

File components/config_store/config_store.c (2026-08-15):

#include "config_store.h"

#include <inttypes.h>
#include <stdio.h>
#include <string.h>

#include "cJSON.h"
#include "esp_log.h"
#include "esp_random.h"
#include "freertos/FreeRTOS.h"
#include "freertos/semphr.h"
#include "nvs.h"
#include "nvs_flash.h"
#include "psa/crypto.h"

static const char *TAG = "config_store";
static const char *NVS_NAMESPACE = "cfg";
static const char *NVS_KEY_BLOB = "device_json";

static device_config_t s_config;
static SemaphoreHandle_t s_mutex;
static uint16_t s_next_var_id = 1;

/* ---------------------------------------------------------------------
 * small helpers
 * ------------------------------------------------------------------- */

static void copy_str(char *dst, size_t dst_size, const char *src)
{
    if (dst_size == 0) {
        return;
    }
    snprintf(dst, dst_size, "%s", src ? src : "");
}

static void bytes_to_hex(const uint8_t *bytes, size_t len, char *out_hex)
{
    static const char hex[] = "0123456789abcdef";
    for (size_t i = 0; i < len; i++) {
        out_hex[2 * i] = hex[bytes[i] >> 4];
        out_hex[2 * i + 1] = hex[bytes[i] & 0x0F];
    }
    out_hex[2 * len] = '\0';
}

static bool hex_to_bytes(const char *hex, uint8_t *out, size_t out_len)
{
    for (size_t i = 0; i < out_len; i++) {
        unsigned int byte;
        if (sscanf(hex + 2 * i, "%2x", &byte) != 1) {
            return false;
        }
        out[i] = (uint8_t)byte;
    }
    return true;
}

/* mbedtls's legacy per-algorithm API (mbedtls/sha256.h) has been
 * removed in this mbedtls version - mbedtls/include only exposes a
 * "private" subtree now. PSA Crypto (psa/crypto.h) is the only public
 * hashing API left; psa_crypto_init() is called once in
 * config_store_init(). */
static void hash_with_salt(const char *plaintext, const uint8_t salt[8], uint8_t out_hash[32])
{
    uint8_t buf[8 + 128];
    size_t plaintext_len = strlen(plaintext);
    if (plaintext_len > sizeof(buf) - 8) {
        plaintext_len = sizeof(buf) - 8; /* defensive clamp; passwords are always far shorter */
    }
    memcpy(buf, salt, 8);
    memcpy(buf + 8, plaintext, plaintext_len);

    size_t hash_len = 0;
    psa_status_t status = psa_hash_compute(PSA_ALG_SHA_256, buf, 8 + plaintext_len, out_hash, 32, &hash_len);
    if (status != PSA_SUCCESS) {
        ESP_LOGE(TAG, "psa_hash_compute failed: %d", (int)status);
        memset(out_hash, 0, 32); /* should never happen; avoid leaving the hash uninitialized */
    }
}

static int json_get_int(const cJSON *obj, const char *key, int def)
{
    const cJSON *j = cJSON_GetObjectItemCaseSensitive(obj, key);
    return (j && cJSON_IsNumber(j)) ? (int)j->valuedouble : def;
}

static double json_get_double(const cJSON *obj, const char *key, double def)
{
    const cJSON *j = cJSON_GetObjectItemCaseSensitive(obj, key);
    return (j && cJSON_IsNumber(j)) ? j->valuedouble : def;
}

static bool json_get_bool(const cJSON *obj, const char *key, bool def)
{
    const cJSON *j = cJSON_GetObjectItemCaseSensitive(obj, key);
    return (j && cJSON_IsBool(j)) ? cJSON_IsTrue(j) : def;
}

static void json_get_str(const cJSON *obj, const char *key, char *dst, size_t dst_size, const char *def)
{
    const cJSON *j = cJSON_GetObjectItemCaseSensitive(obj, key);
    copy_str(dst, dst_size, (j && cJSON_IsString(j)) ? j->valuestring : def);
}

/* ---------------------------------------------------------------------
 * defaults
 * ------------------------------------------------------------------- */

/* Factory-default variables for the three onboard Walter Feels
 * environmental sensors (HDC1080 temperature/humidity, LPS22HB
 * pressure), so a station reports basic ambient conditions out of the
 * box with no portal setup required - students can still edit/disable/
 * delete these like any other variable. device_type values (2/3/4) are
 * I2C_DEVICE_TYPE_HDC1080_TEMP/HDC1080_HUMIDITY/LPS22HB_PRESSURE from
 * i2c_sensors/include/i2c_sensor_registry.h; not #included here to
 * avoid a circular component dependency (i2c_sensors already REQUIRES
 * config_store for config_schema.h). I2C addresses per
 * USER_MANUAL.md §6.5: HDC1080 is fixed at 0x40; LPS22HB is 0x5C or
 * 0x5D depending on its SA0 strap - 0x5C (SA0 low) is assumed here as
 * the more common default, re-check with the portal's "Scan I2C bus"
 * button and edit the address if a station's board doesn't respond. */
#define DEFAULT_ONBOARD_HDC1080_TEMP_DEVICE_TYPE 2
#define DEFAULT_ONBOARD_HDC1080_HUMIDITY_DEVICE_TYPE 3
#define DEFAULT_ONBOARD_LPS22HB_PRESSURE_DEVICE_TYPE 4
#define DEFAULT_ONBOARD_HDC1080_I2C_ADDR 0x40
#define DEFAULT_ONBOARD_LPS22HB_I2C_ADDR 0x5C
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

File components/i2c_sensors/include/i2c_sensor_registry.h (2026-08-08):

#pragma once

#include "config_schema.h"
#include "esp_err.h"

#ifdef __cplusplus
extern "C" {
#endif

/* variable_config_t.addr.i2c.device_type values. Each maps to a
 * driver in this component; add new device types here + a matching
 * driver file + a case in i2c_sensor_registry.c's dispatcher. */
#define I2C_DEVICE_TYPE_ADS111X 0     /* TI ADS1113/1114/1115 16-bit ADC; channel_index 0-7 = the chip's raw MUX select (0-3 differential pairs, 4-7 single-ended) - see ads111x.c */
#define I2C_DEVICE_TYPE_GENERIC_REG16 1 /* fallback: raw signed 16-bit big-endian register read, no scaling */

/* Walter Feels onboard sensors - all on the EXTERNAL I2C connector bus
 * (i2c_bus.h), same as LTC4015; see hdc1080.c's header comment for why
 * this isn't the separate BOARD_PIN_ONBOARD_I2C_* bus despite the
 * naming. channel_index is unused (0) for the fixed single-purpose
 * device types below. */
#define I2C_DEVICE_TYPE_HDC1080_TEMP 2     /* TI HDC1080 temperature - see hdc1080.c */
#define I2C_DEVICE_TYPE_HDC1080_HUMIDITY 3 /* TI HDC1080 humidity - see hdc1080.c */
#define I2C_DEVICE_TYPE_LPS22HB_PRESSURE 4 /* ST LPS22HB pressure - see lps22hb.c */
#define I2C_DEVICE_TYPE_LPS22HB_TEMP 5     /* ST LPS22HB temperature - see lps22hb.c */
/* LTC4015 battery monitor; channel_index selects which telemetry
 * register (0=VBAT, 1=VIN, 2=IBAT, 3=DIE_TEMP) - see ltc4015.c. */
#define I2C_DEVICE_TYPE_LTC4015 6

/* device_type-specific drivers, called by the registry dispatcher -
 * not normally called directly. */
esp_err_t ads111x_read_channel(uint8_t i2c_addr, uint8_t channel, uint8_t gain, double *out_value);
esp_err_t generic_read_register16(uint8_t i2c_addr, uint8_t reg, double *out_value);
esp_err_t hdc1080_read_temperature(uint8_t i2c_addr, double *out_value);
esp_err_t hdc1080_read_humidity(uint8_t i2c_addr, double *out_value);
esp_err_t lps22hb_read_pressure(uint8_t i2c_addr, double *out_value);
esp_err_t lps22hb_read_temperature(uint8_t i2c_addr, double *out_value);
esp_err_t ltc4015_read_channel(uint8_t i2c_addr, uint8_t channel, double *out_value);

/* Dispatches to the driver matching device_type. `gain` is only
 * meaningful for I2C_DEVICE_TYPE_ADS111X (see ads111x.c) and ignored
 * otherwise. */
esp_err_t i2c_sensor_read(uint8_t device_type, uint8_t i2c_addr, uint8_t channel_index, uint8_t gain,
                          double *out_value);

/* Matches sensor_bus_read_fn_t (sampling_engine.h) - register this
 * directly with sampling_engine_register_bus_driver(BUS_TYPE_I2C, ...). */
esp_err_t i2c_variable_read(const variable_config_t *var, double *out_value);

#ifdef __cplusplus
}
#endif

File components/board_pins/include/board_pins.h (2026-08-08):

#pragma once

/*
 * Board pin map - two variants, selected via `idf.py menuconfig` ->
 * "Walter Sensor Node Board Selection" (components/board_pins/Kconfig.projbuild),
 * independent of but paired with the chip target (`idf.py set-target`):
 *
 *  - BOARD_VARIANT_WALTER_FEELS (default): the production Walter +
 *    Walter Feels carrier board. Requires chip target esp32s3. SDI-12,
 *    I2C, and SD card pins are taken directly from the user-supplied
 *    Walter Feels schematic and are considered confirmed; still
 *    placeholders (BOARD_PIN_NOT_SET) where nothing in the supplied
 *    schematic pages showed a value: SD card-detect, status LED,
 *    force-AP button. Enable-pin ACTIVE LEVELS (TX_EN/RX_EN etc.) are
 *    an inference from the SN74LV1T126 datasheet (active-HIGH OE), not
 *    something visible in a schematic - verify with a meter if SDI-12
 *    doesn't work.
 *
 *  - BOARD_VARIANT_ESP32_DEVKIT_TEST: a plain ESP32 DevKit V1 with no
 *    Walter Feels board at hand, for testing the firmware against real
 *    I2C sensors (e.g. two ADS1115 ADCs at different addresses) before
 *    the production board arrives. Requires chip target esp32 (classic).
 *    Only I2C is wired; SDI-12/SD card/cellular are left unconfigured,
 *    which each subsystem already handles gracefully (see below).
 *
 * Each subsystem's init function calls board_pin_is_set() on the pins
 * it needs and refuses to start (logging an error) rather than driving
 * an unconfirmed pin - so it's safe to build and flash with any pin
 * still unset; only the affected subsystem stays disabled.
 */

#include <stdbool.h>
#include <stdint.h>

#include "driver/gpio.h"

#define BOARD_PIN_NOT_SET GPIO_NUM_NC

#if CONFIG_BOARD_VARIANT_ESP32_DEVKIT_TEST

/* ---- Generic ESP32 DevKit V1 (I2C-only test rig) ----
 * No SDI-12 transceiver, SD card, or cellular modem wired - all left
 * unconfigured. sdi12_bus_init()/sd_logger_init()/cellular_transport_init()
 * all fail gracefully (logged, non-fatal) without these, and
 * sampling_engine falls back to the synthetic stub_sensor for
 * BUS_TYPE_SDI12 automatically (see app_main.c). */
#define BOARD_PIN_SDI12_TXD BOARD_PIN_NOT_SET
#define BOARD_PIN_SDI12_RXD BOARD_PIN_NOT_SET
#define BOARD_PIN_SDI12_TX_EN BOARD_PIN_NOT_SET
#define BOARD_PIN_SDI12_RX_EN BOARD_PIN_NOT_SET
#define BOARD_PIN_SDI12_BUS_POWER BOARD_PIN_NOT_SET
#define BOARD_PIN_RS485_TX_EN BOARD_PIN_NOT_SET
#define BOARD_PIN_RS485_RX_EN BOARD_PIN_NOT_SET
#define BOARD_PIN_RS232_TX_EN BOARD_PIN_NOT_SET
#define BOARD_PIN_RS232_RX_EN BOARD_PIN_NOT_SET

/* Standard ESP32 DevKit V1 I2C pins (the de facto default used by
 * Arduino's Wire library and most DevKit silkscreens/breakouts). Wire
 * two ADS1115 boards here, each given a distinct address so they
 * coexist on one bus - either via the generic ADS1115 ADDR pin
 * (GND=0x48, VDD=0x49, SDA=0x4A, SCL=0x4B) or a breakout's own
 * jumpers (e.g. Soldered's ADS1115 board: default=0x48, JP3=0x39,
 * JP4=0x4A, JP5=0x4B - close only one at a time). Confirm your actual
 * boards' addresses with the portal's "Scan I2C bus" button rather
 * than assuming - configure one "variable" per ADC input you want in
 * the portal, with device_type 0 (ADS111x) and the channel index set
 * via the portal's dropdown (supports both single-ended and
 * differential pairs - see
 * ads111x.c's header comment for the full mapping). */
#define BOARD_I2C_PORT (-1) /* -1 = let the I2C driver auto-assign a free port */
#define BOARD_PIN_I2C_SDA GPIO_NUM_21
#define BOARD_PIN_I2C_SCL GPIO_NUM_22
#define BOARD_PIN_I2C_BUS_POWER BOARD_PIN_NOT_SET /* no switched rail on a plain DevKit - power sensors from 3V3/5V directly */
#define BOARD_I2C_CLOCK_HZ 100000

#define BOARD_PIN_SD_CLK BOARD_PIN_NOT_SET
#define BOARD_PIN_SD_CMD BOARD_PIN_NOT_SET
#define BOARD_PIN_SD_D0 BOARD_PIN_NOT_SET
#define BOARD_PIN_SD_CARD_DETECT BOARD_PIN_NOT_SET

#define BOARD_PIN_STATUS_LED BOARD_PIN_NOT_SET /* many DevKit V1 clones have an onboard LED on GPIO2, but not universally - verify before wiring logic to it */
#define BOARD_PIN_FORCE_AP_BUTTON BOARD_PIN_NOT_SET

/* No switched 3.3V rail on a plain DevKit - sensors are powered from
 * 3V3/5V directly, so board_pins_enable_3v3_sw() is a no-op here. */
#define BOARD_PIN_3V3_SW_EN BOARD_PIN_NOT_SET

/* No onboard HDC1080/LPS22HB/LTC4015 on a plain DevKit - onboard_i2c_bus_init()
 * fails gracefully (logged, non-fatal) without these pins set, same as
 * every other optional subsystem on this board variant. */
#define BOARD_ONBOARD_I2C_PORT (-1)
#define BOARD_PIN_ONBOARD_I2C_SDA BOARD_PIN_NOT_SET
#define BOARD_PIN_ONBOARD_I2C_SCL BOARD_PIN_NOT_SET
#define BOARD_PIN_ONBOARD_I2C_EN BOARD_PIN_NOT_SET
#define BOARD_ONBOARD_I2C_CLOCK_HZ 100000

#else /* BOARD_VARIANT_WALTER_FEELS (default) */
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

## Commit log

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2026-07-13 Add sampling engine, Welford aggregator, and stub sensor source
    sampling_engine owns per-bus-type scheduling tasks that call into a
    registered sensor_bus_read_fn_t (kept hardware-agnostic so real
    sdi12_bus/i2c_bus drivers can be swapped in later without touching this
    code) and an aggregation task that folds samples into a per-variable
    Welford accumulator, finalizing raw/mean/min/max/stddev at each
    variable's log_interval and fanning results out to any number of
    registered sink queues (sd_logger, mqtt_publish_task, etc. in later
    stages).
    stub_sensor provides a synthetic sine-wave+noise reading so the full
    sample -> aggregate -> sink pipeline is testable before real sensor
    drivers exist; app_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
    [app_main.c, sampling_engine.c]
2026-07-13 Add SD card CSV logger
    Mounts the microSD slot in SPI mode (esp_vfs_fat_sdspi_mount) using the
    board_pins SD pin set, and writes one long/tidy-format CSV row per
    finalized aggregate_result_t (one file per UTC day under /sdcard/data).
    Long format sidesteps the need to know the full variable set up front
    or realign differently-timed per-variable log intervals into a single
    wide row.
    Registers as a sampling_engine result sink alongside the existing
    debug log sink. Mount failure (no card, pins not configured) is
    non-fatal - sd_logger_is_ready()/get_sink_queue() let the rest of the
    system degrade gracefully instead of blocking boot.
    [app_main.c]
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2026-07-13 Add WiFi STA connection handling and SNTP time sync
    net_manager now layers a WiFi STA connection on top of the existing
    SoftAP when net_settings.transport is TRANSPORT_WIFI: connects on
    WIFI_EVENT_STA_START, retries on disconnect with a fixed 5s backoff,
    and tracks connected state via IP_EVENT_STA_GOT_IP. The desired wifi
    mode (NULL/AP/STA/APSTA) is now computed from both ap_policy's state
    and the configured transport, so the AP keeps working independently of
    whether WiFi is also the data-plane transport, per spec. Transport
    changes still require a reboot (mode/credentials are only read once at
    init) - unchanged design decision, just now actually load-bearing.
    Adds time_sync: an opportunist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
    [app_main.c, sampling_engine.c]
2026-07-13 Add MQTT dual-backend bridge with esp-mqtt (WiFi) implementation
    mqtt_client_bridge registers as a sampling_engine result sink and
    picks one backend at startup based on net_settings.transport (esp-mqtt
    now for WiFi; the on-modem WalterModem MQTT client is a stage-9 TODO
    for cellular) - the rest of the app only calls the transport-agnostic
    bridge. Stays fully inert until MQTT is enabled via the portal, and
    reacts to MQTT settings edits (host/credentials/enable/...) without a
    reboot by diffing config_store's generation-tagged settings against
    the last-applied ones.
    Publishes one JSON payload per variable per log interval to
    "<topic_prefix>/<sanitized variable name>", including only the
    aggreg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
    [app_main.c]
2026-07-13 Add bit-banged SDI-12 driver
    sdi12_bus implements the SDI-12 v1.4 physical layer (1200 baud, 7
    data bits, even parity, 1 stop bit, inverted mark/space polarity) via
    manual GPIO bit-banging rather than the RMT peripheral: a GPIO
    interrupt detects each character's start-bit edge and wakes the
    calling task (avoiding a busy-wait across the sensor's up-to-750ms
    response gap), then a short esp_rom_delay_us busy-wait samples that
    one character's bits at their centers. An internal mutex serializes
    callers since sampling_engine's periodic scheduler and web_portal's
    on-demand preview/scan can both call in from different tasks.
    sdi12_protocol.c layers the aM!->wait->aD0! measurement sequence,
    value pa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
    [api_bus.c, app_main.c, sdi12_bus.c]
2026-07-13 Add I2C bus wrapper and sensor registry (ADS111x + generic fallback)
    i2c_bus wraps ESP-IDF's driver/i2c_master.h with a small per-address
    device-handle cache (the new i2c_master API requires an explicit
    device handle before transacting) behind a mutex, so sampling_engine's
    periodic scheduler and web_portal's on-demand scan/preview can share
    the bus safely from different tasks - same pattern as sdi12_bus.
    i2c_sensors adds a device_type-dispatched registry: ADS111x (16-bit
    ADC, fixed +/-4.096V PGA / single-shot / 128SPS, returns volts) covers
    the "ADC for example" case from the spec, plus a generic raw-16-bit-
    register fallback for sensors without a dedicated driver yet.
    Wires both into web_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
    [ads111x.c, api_bus.c, app_main.c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]
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2026-07-13 Hardening pass: task watchdog, SDI-12 wait-time cap, and README
    Registers aggregation_task, sd_writer_task, and mqtt_publish_task with
    the ESP-IDF task watchdog (panic+reboot on trip, appropriate for an
    unattended field deployment) - each already had bounded per-iteration
    blocking (or was changed to, for sd_writer_task's previously-infinite
    queue wait) so a genuine hang gets caught without false trips.
    Deliberately leaves the SDI-12/I2C bus scheduler tasks unregistered:
    sensor reads have inherently variable, sensor-advertised timing that
    doesn't fit a fixed watchdog timeout.
    Caps SDI-12's aM! advertised wait time to 180s (spec allows up to
    999s) so a misbehaving/misparsed response can't blo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
    [app_main.c, sampling_engine.c]
2026-07-13 Fix SDI-12 and SD card wiring against the real Walter Feels schematic
    The user supplied the actual SDI-12 transceiver sheet and the Walter
    module's 28-pin header pinout. Both corrected wrong assumptions baked
    into the earlier placeholder-driven design:
    SDI-12 is NOT a single shared half-duplex GPIO line - Walter Feels
    puts it on a UART-style bus (SER_TX=IO40, SER_RX=IO41) through two
    SN74LV1T126 tri-state buffers, each with its own enable pin
    (SDI12_TX_EN=IO10, SDI12_RX_EN=IO9), and that bus is further shared
    with RS485/RS232 transceivers via their own enables. Reworked
    sdi12_bus.c accordingly: separate fixed-direction TXD/RXD pins (no
    more gpio_set_direction() toggling of a shared pin), TX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
    [board_pins.h, i2c_bus.c, sdi12_bus.c]
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2026-07-13 Wire gnss_position/device_id into app_main; update README
    Logs device_id in the boot banner. Starts gnss_position after a
    successful cellular_transport_init(), gated the same way as the rest
    of the cellular stack (transport==CELLULAR, decided once at boot).
    README now covers the device ID / MQTT topic convention and flags
    GNSS fix acquisition alongside the rest of cellular_transport's
    unverified WalterModem calls.
    [app_main.c]
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2026-07-22 Support ADS1115 differential channels; add a channel-select UI
    ads111x_read_channel() previously forced single-ended mode
    (MUX = 0x4 + channel, channels 0-3 only). channel_index is now passed
    straight through as the chip's raw 3-bit MUX select, matching the
    ADS111x datasheet's own table: 0-3 select the four differential pairs
    (AIN0-AIN1, AIN0-AIN3, AIN1-AIN3, AIN2-AIN3), 4-7 select single-ended
    AIN0-AIN3 - covering every mode the chip supports, not just
    single-ended.
    The portal's variable form no longer asks for a bare "channel index"
    number for ADS111x - it's a dropdown listing all 8 modes by name
    (e.g. "AIN0 - AIN1 (differential)"), toggled against a plain
    register-address field when devi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
    [ads111x.c, board_pins.h, i2c_sensor_registry.h]
2026-07-22 Correct ADS1115 addressing docs: 0x39 is a legitimate Soldered address
    Confirmed via Soldered's own documentation (docs.soldered.com/adc/hardware/):
    their ADS1115 breakout defaults to 0x48 with no jumper closed, and
    remaps to 0x39/0x4A/0x4B via onboard jumpers JP3/JP4/JP5 respectively
    (closing only one at a time) - a different scheme from the generic
    ADS1115 ADDR-pin table (GND/VDD/SDA/SCL -> 0x48/0x49/0x4A/0x4B).
    Previous wording cast unwarranted doubt on 0x39 as "non-standard" -
    replaced with accurate guidance covering both addressing schemes.
    [board_pins.h]
2026-07-22 Fix esp32 (DevKit) target build against ESP-IDF v6.0.2
    cJSON and esp-mqtt are no longer in-tree components in this ESP-IDF
    version (moved to the component registry as espressif/cjson and
    espressif/mqtt) - switch all REQUIRES accordingly. Gate the
    dptechnics/walter-modem dependency and every WalterModem-dependent code
    path in cellular_transport/mqtt_client behind esp32s3 (that package has
    no build for plain esp32), and add spi_flash to main's REQUIRES
    (esp_flash.h moved out of the default include set).
    Also fixes issues surfaced by an actual esp32 build/boot: mbedtls's
    legacy mbedtls/sha256.h API is gone in this mbedtls version (replaced
    by PSA Crypto's psa_hash_compute()), plus a handful of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
    [board_pins.h, config_store.c, i2c_bus.c]
2026-07-22 Fix stack overflows found on first real hardware boot
    Two separate overflows, both from arrays/call-depth that don't fit the
    default 4KB task stacks used throughout this project:
    - The main task (default 3584B stack) overflowed inside
    config_store_init()'s password hashing - PSA Crypto's driver-dispatch
    call chain is noticeably deeper than the legacy mbedtls API it
    replaced. Bump CONFIG_ESP_MAIN_TASK_STACK_SIZE to 8192.
    - sampling_engine's per-bus scheduler task (sdi12_sched/i2c_sched)
    overflowed its 4096B stack from two full MAX_VARIABLES=32 struct
    arrays declared as plain locals (~3KB just for those). Heap-allocate
    them once at task start instead (two concurrent instances of t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
    [sampling_engine.c]
2026-07-22 Add per-variable ADS1115 gain (PGA) setting
    The ADS1115 driver had a single hardcoded PGA (+/-4.096V), which
    doesn't fit every signal a student might wire up - e.g. clips a 0-5V
    sensor above 4.096V, while wasting resolution on a 0-1.5V one. Make
    gain a per-variable field (i2c_addr_t.gain, the chip's raw 3-bit PGA
    select, same pattern as the existing channel_index), threaded through
    i2c_sensor_read()/ads111x_read_channel(), with a portal dropdown next
    to the channel selector. Missing/old configs default to gain=1
    (+/-4.096V) to match the previous hardcoded behavior.
    Also documents that this setting doesn't change the chip's absolute
    maximum input voltage (VDD+0.3V regardless of gain) - a 0-5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
    [ads111x.c, config_schema.h, i2c_sensor_registry.c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]
2026-07-22 Add flat MQTT telemetry mode for ThingsBoard/AWS IoT compatibility
    The existing scheme publishes each variable to its own topic
    ("<topic_prefix>/<device_id>/<name>") with a generic {"mean":...,
    "stddev":...} payload - fine for a rule engine designed around it, but
    platforms like ThingsBoard only read one fixed topic
    (v1/devices/me/telemetry) and identify the device from the connection's
    access-token username, not the topic path. Publishing to the old
    per-variable topic scheme was silently dropped: the MQTT session still
    connects fine (so the device shows "online"), but no telemetry ever
    lands, with nothing in the firmware able to detect the mismatch since
    MQTT PUBLISH doesn't NACK on an unre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
    [config_schema.h, config_store.c]
2026-07-22 Add per-variable linear calibration and Walter Feels onboard sensors
    Calibration: every variable now has calibration_a/calibration_b
    (default 1.0/0.0, a no-op), applied as calibrated = a*raw + b right
    after each successful read, before the value reaches the aggregator -
    so raw/mean/min/max/stddev all reflect the calibrated value. Typical
    use: correcting a voltage divider's ratio, or a two-point sensor cal.
    Onboard sensors: integrates Walter Feels' built-in HDC1080
    (temp/humidity), LPS22HB (pressure/temp), and LTC4015 (battery
    monitor) as new I2C device types, exposed through the same
    variable/device_type/channel_index mechanism as external I2C sensors.
    HDC1080/LPS22HB live on a second, phys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
    [app_main.c, board_pins.h, config_schema.h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]
2026-07-23 Average ADS111x readings over 100ms to reject 50/60Hz mains hum
    Each "sample" was a single instantaneous single-shot conversion; since
    sample_interval_ms is seconds apart, any 50Hz ripple riding on the
    measured signal would alias into the aggregator's mean/stddev as a
    random-phase snapshot each time, since the ADS1115's own filter only
    rejects noise above its ~64Hz Nyquist at 128SPS.
    Now each read is the average of 10 single-shot conversions spread over
    100ms - a boxcar average of that length has spectral nulls at every
    multiple of 10Hz, which includes both 50Hz and 60Hz simultaneously
    (the same line-cycle-rejection trick precision multimeters use), and
    generally attenuates anything above ~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
    [ads111x.c]
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2026-08-04 Add the missing top-level CMakeLists.txt walter-modem CMake target patch
    Follow-up to 7375a01 - that commit's message described patching
    walter-modem's CMake target (via idf_component_get_property +
    target_link_libraries) to fix its missing esp_driver_uart/esp_driver_gpio
    requirements, but the actual CMakeLists.txt diff wasn't staged.
    [app_main.c, board_pins.h]
2026-08-04 Add TOA5/wide-format SD logging; fix portal UI and cellular safety issues
    SD logging (the main feature): a new sd_settings_t.log_format setting
    (LONG/WIDE_SIMPLE/WIDE_TOA5) alongside the existing per-event-row CSV.
    The wide formats write one row per "scan" - one column per
    variable+aggregate, grouped into a separate file per distinct
    log_interval_ms (variables sharing an interval land in the same file/
    row, like a Campbell Scientific datalogger's output tables). Row
    assembly buffers incoming per-variable aggregate_result_t's into a
    pending row per interval group, flushing on completion, on the next
    scan starting early, or on a timeout grace period so a dead sensor
    can't stall a whole group i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
    [config_schema.h, config_store.c]
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2026-08-04 Fix SDI-12 parity (even -> odd) and enable heap corruption diagnostics
    tx_char() was computing even parity, but SDI-12's character framing is
    7O1 (7 data bits, ODD parity, 1 stop bit) per spec. A compliant sensor
    silently ignores any character with a parity error rather than
    responding with an error - indistinguishable from "nothing connected".
    This was the actual root cause of a real, spec-verified-working sensor
    (tested good on a Campbell CR350) never responding to anything on real
    hardware, including a bus scan.
    Also enable CONFIG_HEAP_POISONING_COMPREHENSIVE to chase down a
    separate `block_trim_free`/`block must be free` TLSF assert seen on
    real hardware: that assert only fires later, o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
    [sdi12_bus.c]
2026-08-04 Add SDI-12/cellular hardware bring-up diagnostics; try PDP type IPv4v6
    SDI-12: add a temporary sdi12_bus_debug_tx_toggle_test() that slowly
    toggles TXD (meter-visible, unlike a real 833us/bit transaction) and
    counts GPIO edges seen on RXD via loopback on the shared bus. On real
    hardware this proved TX genuinely reaches the bus (confirmed by
    multimeter, 0-5V swing) but RXD sees zero edges despite RX_EN sitting
    enabled the whole time - isolating the fault to the receive chain
    (U6/RX_EN/RXD) rather than TX_EN polarity, protocol timing, or the
    already-fixed parity bug.
    Cellular: enable the WalterModem SDK's own hidden ESP_LOGD "TX:"/"RX:"
    AT command trace (compiled out at this project's default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
    [app_main.c, sdi12_bus.c]
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2026-08-04 Revert incorrect SDI-12 parity change - spec requires EVEN, not odd
    An earlier commit changed SDI-12's parity computation from even to odd,
    asserting this as a confirmed spec fact. That assertion was wrong: the
    SDI-12 spec's serial character format is 7E1 (7 data bits, EVEN parity,
    1 stop bit), confirmed against the official spec text and two
    independent real-world implementations (EnviroDIY/Arduino-SDI-12,
    ESPSoftwareSerial-based ESP32 SDI-12 drivers using SWSERIAL_7E1). The
    original even-parity code was correct all along.
    This was caught by comparing against a reference ESP32 SDI-12
    implementation on request, after further hardware bring-up (on a
    second, separate Walter Feels board) isola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
    [sdi12_bus.c]
2026-08-04 Add manual SDI-12 RX chain isolation test (independent of our own TX)
    sdi12_bus_debug_rx_monitor() enables RX_EN and listens on RXD for a
    configurable window, logging each detected edge live, without driving
    TXD/TX_EN at all. This tests the RX_EN/RXD/U6 receive chain against an
    externally/manually driven signal on the bus, fully isolated from this
    board's own TX circuit (U5) - which is already independently confirmed
    working via sdi12_bus_debug_tx_toggle_test(). Swapped in for the boot-
    time diagnostic in app_main.c with a 30s window to allow time to
    physically drive the SDI-12 DATA line by hand.
    [app_main.c, sdi12_bus.c]
2026-08-04 Fix RS485/RS232 RX_EN polarity - real root cause of dead SDI-12 RX
    Confirmed via DPTechnics support (Daan): fully disabling the RS485 and
    RS232 transceivers on Walter Feels' shared SER_TX/SER_RX bus requires
    *_TX_EN=LOW AND *_RX_EN=HIGH - not both LOW, as this codebase originally
    assumed (matching SDI-12's own simple active-high buffer OE
    convention). RS485_RX_EN/RS232_RX_EN are apparently active-low
    receiver-enables (a common RS-485 transceiver DE/~RE pattern), so
    driving them LOW left both transceivers' receivers actively driving the
    shared SER_RXD line at the same time as SDI-12's own U6 output - real
    bus contention, and the actual explanation for RXD never seeing a
    coherent signal despit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
    [app_main.c, board_pins.h, sdi12_bus.c]
2026-08-05 Clean up SDI-12/cellular bring-up diagnostics now that both work
    Real SDI-12 sensor confirmed working end-to-end after the RS485/RS232
    RX_EN fix, and cellular/MQTT confirmed working after the SIM-contact
    hardware issue was resolved by swapping modules. Remove the temporary
    diagnostics added along the way:
    - sdi12_bus_debug_tx_toggle_test() / sdi12_bus_debug_rx_monitor() and
    the edge-counter they used, plus the boot-time call in app_main.c and
    the now-unneeded esp_timer component dependency.
    - The WalterModem SDK's AT command TX:/RX: trace logging
    (esp_log_level_set + CONFIG_LOG_MAXIMUM_LEVEL_DEBUG) and the
    AT+CPIN? SIM-state diagnostic query.
    Finalized the SDI-12 header/board_pins.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
    [app_main.c, sdi12_bus.c]
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2026-08-05 Add portal button to reset all stored settings
    New config_store_factory_reset() erases the "cfg" NVS namespace only
    (not a full nvs_flash_erase() - that would also wipe unrelated NVS
    state like PHY calibration data for no benefit, since WiFi STA
    credentials aren't stored in the WiFi driver's own NVS blob here;
    net_manager.c sources them from this same namespace and calls
    esp_wifi_set_config() explicitly every boot).
    Wired up via a new POST /api/system/factory_reset endpoint (mirrors
    reboot_handler()'s reboot-after-response-flushed pattern) and a "Reset
    all settings" button in the portal's System section, gated behind the
    new uiConfirm() modal with a clearly worded, hard-to-misclick warning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
    [config_store.c]
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2026-08-05 Fix LTC4015 VBAT always reading 0; add battery sync-with-publish mode
    Root cause of "battery voltage reported as 0 with a real battery
    connected": the LTC4015's A/D measurement system only runs while input
    power is present (VIN > VBAT) by default - confirmed against the
    datasheet (4015fb, CONFIG_BITS sub-address 0x14). With no active
    charging input, telemetry registers (VBAT included) just sit at their
    power-on-reset value of 0 forever, regardless of what's actually
    connected to BAT. Fix: set force_meas_sys_on (CONFIG_BITS bit 4) once
    per boot via read-modify-write (so as not to disturb other config bits
    like suspend_charger/mppt_en_i2c), making the ADC run continuously -
    the right tradeoff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
    [config_schema.h, config_store.c, ltc4015.c]
2026-08-05 Add I2C bus recovery for a device stuck holding SDA low after reboot
    Real hardware symptom: after a reboot (including one triggered via the
    portal's reboot/factory-reset buttons), the external I2C bus can end up
    completely wedged - every single address times out on a scan, not just
    one sensor, and it never recovers on its own; only a full power cycle
    fixed it previously. Reproduced even on firmware predating any of this
    session's I2C-adjacent changes, ruling out anything application-level.
    Leading suspect: GPIO0 doubles as both the switched I2C rail's (3V3_SW)
    enable pin and the boot-strap pin, so its state isn't fully guaranteed
    for the first few instructions of a reset - a brief power gli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
    [i2c_bus.c]
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2026-08-05 Add runtime I2C bus reset when a transaction genuinely times out
    The earlier boot-time-only recovery (recover_stuck_bus(), called once
    from i2c_bus_init()) can't catch a device that wedges the bus later,
    during normal operation - and that's a real, repeatable failure mode
    on real hardware: a device stuck holding SDA low minutes into uptime,
    confirmed via a live multimeter reading, well after boot's one-shot
    check already ran and found nothing wrong yet.
    Extract the master-bus construction into create_master_bus() so it can
    be reused, and add reset_bus_locked(): tears down the current master
    bus (removing all cached device handles first), re-runs the same
    stuck-SDA GPIO recovery boot uses, t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
    [i2c_bus.c]
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2026-08-08 config_store: ship onboard env sensors enabled by default
    A fresh/factory-reset device previously started with zero configured
    variables. Now it ships with Board_Temperature, Board_Humidity
    (HDC1080) and Board_Pressure (LPS22HB) enabled out of the box, sampled
    every 1 minute and logged (mean) every 10 minutes - basic ambient
    conditions with no portal setup required, while still fully
    editable/removable like any other variable.
    Only affects genuinely fresh devices: config_store_from_json() always
    overlays a saved config's own "variables" array over these defaults, so
    existing deployments are unaffected.
    [config_store.c]
2026-08-08 i2c_sensors: fix HDC1080/LPS22HB wired to the wrong I2C bus
    board_pins.h assumed HDC1080/LPS22HB lived on a separate "onboard"
    bus (onboard_i2c_bus, GPIO12/11) from the external connector - real-
    hardware evidence said otherwise: a factory-fresh board with nothing
    plugged into the external connector still found HDC1080 (0x40),
    LPS22HB (0x5C), LTC4015 (0x68, already known to be external) and an
    LSM6DSM IMU (0x6A) all by scanning the *external* bus, while
    onboard_i2c_bus cleanly NACKed every read (not timed out) - consistent
    with that pin pair only reaching a real but genuinely unpopulated CO2
    sensor header, later confirmed directly by the board owner.
    Rerouted hdc1080.c/lps22hb.c from onboar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
    [board_pins.h, hdc1080.c, i2c_bus.c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]
2026-08-08 i2c_sensors: fix LTC4015 battery voltage always reading 0V
    The LTC4015's measurement ADC only runs while charging input power is
    present by default; force_meas_sys_on overrides that, but the fix set
    its "already handled" flag unconditionally before even attempting the
    read - so a single transient failure (e.g. the very first call landing
    before the chip/bus had settled right after boot) permanently disabled
    it for the rest of the session. Every subsequent read still succeeded
    (it's a real register), it just never got updated - which is why this
    looked like "battery voltage always reads exactly 0.000 V, no error
    logged" rather than an obvious failure.
    The flag is now only set once the bit is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
    [ltc4015.c]
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
